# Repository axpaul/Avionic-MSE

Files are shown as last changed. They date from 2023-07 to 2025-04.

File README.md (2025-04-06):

# Avionic-MSE
*MSE experimental rocket avionic (On-board electronics), Version 2023 launched at C'space*

> *© 2023 Paul Miailhe, all rights reserved.*  
> *Material licensed under [→ CC BY-NC-SA 4.0](https://creativecommons.org/licenses/by-nc-sa/4.0)*

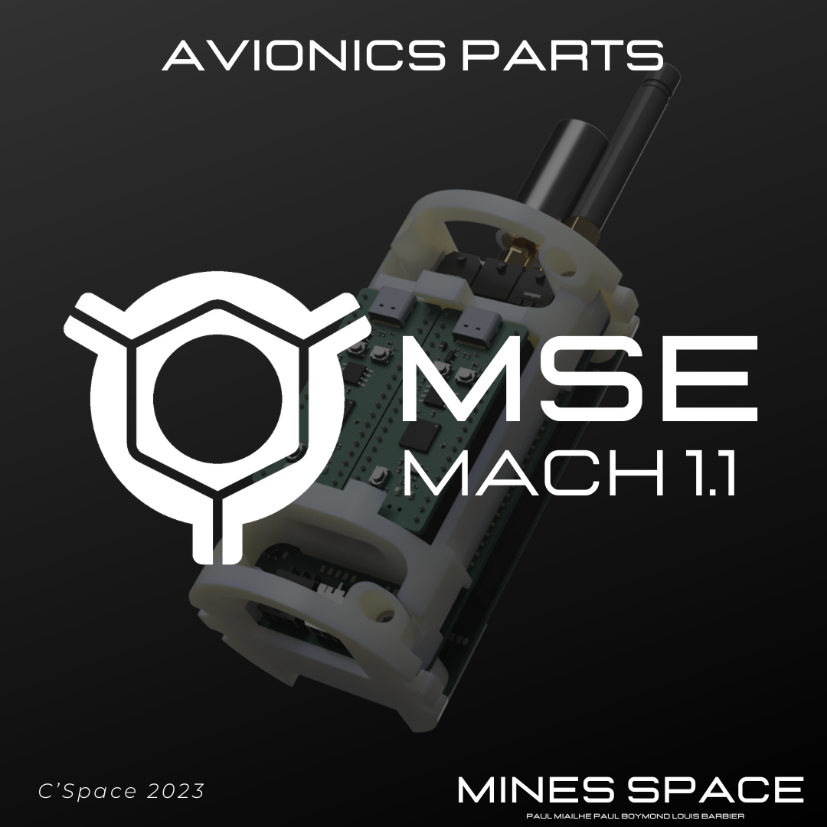
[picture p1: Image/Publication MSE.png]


Grabcad :
- https://grabcad.com/library/avionics-system-for-mse-rocket-1

---

# Projet MarSoniquE (MSE)

Le projet **MarSoniquE (MSE)**, également connu sous le nom de **Marsaut E**, vise à concevoir une fusée expérimentale robuste et adaptée aux vols supersoniques pour mener des études spécifiques dans ce domaine. À ce jour, aucune fusée expérimentale n’a réalisé de vol nominal avec des caractéristiques similaires lors des événements du **C’Space** sur le site d’essai du 1er RHP. En s’appuyant sur une démarche Open Source, le projet cherche à fournir un cadre technique permettant de relever ce défi.

Le développement s’appuie sur l’expérience acquise avec les avioniques des projets précédents **Marsaut 0** et **Marsaut 1**. L’objectif principal est de créer une structure résistante aux contraintes mécaniques d’un vol supersonique, avec des accélérations atteignant **28g** et des vibrations significatives dans le domaine transsonique. Par ailleurs, la crise actuelle des semi-conducteurs impose des choix restrictifs en termes de composants.

---

## Composants techniques

### Microcontrôleur
- **RP2040** : Microcontrôleur de Raspberry basé sur un cœur **ARM Cortex-M0+**.  
  Il intègre des fonctionnalités telles que la gestion de mémoire flash (Quad-SPI) et répond aux besoins du projet.

---

### Instrumentation

#### Capteurs analogiques
- **26PCGFA6D** : Capteur de pression différentiel pour la sonde Pitot, mesurant jusqu’à **250 PSI**.
  - **Amplificateur** : Utilisation de l’**INA121** pour amplifier proprement le signal.
  - **Convertisseur analogique-numérique** : **ADS1014** pour transformer le signal amplifié en données numériques exploitables.

#### Capteurs numériques
- **IMU MPU9250** : Capteur inertiel 6 axes, capable de mesurer des accélérations jusqu’à **16g**.  
- **LPS22HB** : Altimètre combinant mesures de pression et de température.  
- **GPS MAX-M10S** : Module GPS compact, opérationnel jusqu’à **80 000 m d’altitude**, **500 m/s** de vitesse et avec une dynamique maximale de **4g**.

---

### Transmission radio
- **SX1276** : Transcepteur LoRa fonctionnant sur **868 MHz**, permettant une communication longue portée et fiable.  
  Il est conçu pour fonctionner efficacement dans des conditions de faible signal grâce à sa sensibilité élevée et sa réduction de bruit intégrée.

---

### Stockage
- **W25Q128JV** : Mémoire flash **SPI de 128 Mbits** utilisée pour l’enregistrement des données en vol.

---

### Alimentation
- **LM340AT** : Régulateur de tension fournissant des tensions fixes de **5V**, **12V** et **15V**, avec une capacité de courant de **1A**.  
- **1210L110/16WR** : Fusible réarmable **PTC** protégeant le circuit contre les surintensités.

---

### Drivers et circuits
- **DRV8871DDARQ1** : Contrôleur de moteur à courant continu.  
  - Tension d’alimentation : **6,5V à 45V**.  
  - Courant de sortie : jusqu’à **3,6A**.  
  Ce composant est utilisé pour piloter les systèmes mécaniques, tels que la trappe de récupération.

- **74HC14D,653** : Porte logique inverseuse Schmitt.  
  Elle stabilise les signaux bruités des fins de course des moteurs et garantit un fonctionnement sûr du système de récupération.

---

## Architecture des cartes et choix des composants

### Cartes développées en interne

Deux cartes principales de l’avionique de la fusée ont été spécialement conçues et fabriquées pour répondre aux exigences spécifiques du projet :

1. **Carte avionique** :  
   - Regroupe les composants essentiels tels que le module **LoRa (SX1276)**, le **GPS (MAX-M10S)**, les **drivers moteurs** et les **portes inverseuses (74HC14D,653)** pour le traitement des signaux.  
   - Inclut également un **buzzer** destiné aux alertes sonores durant les phases critiques.

2. **Carte interface** :  
   - Assure la gestion de l’alimentation ainsi que l’isolation numérique pour protéger et séparer les signaux.  
   - Offre des connecteurs dédiés pour accueillir des capteurs et des cartes auxiliaires, y compris celles équipées de microcontrôleurs.

Ces cartes sur mesure ont été développées pour répondre aux contraintes mécaniques, environnementales et fonctionnelles du projet, tout en garantissant une intégration modulaire et flexible.

---

### Cartes commerciales intégrées

En complément des cartes développées en interne, des cartes électroniques standard commercial ont été choisies pour leur disponibilité et leur coût réduit, tout en répondant aux besoins du projet :
- **RP2040-YD avec 128 Mbits de flash** : Une carte microcontrôleur RP2040 compacte équipée de mémoire flash et conçue sous le format Pico.  
- **Carte capteurs 10DOF** : Fournie par **Waveshare**, cette carte intègre des capteurs inertiels et un baromètre pour mesurer des paramètres comme les accélérations et la pression. Plus d'informations disponibles ici : [Waveshare Pico-10DOF-IMU](https://www.waveshare.com/pico-10dof-imu.htm).

---

### Synoptic

Le schéma synotique du projet avionique :
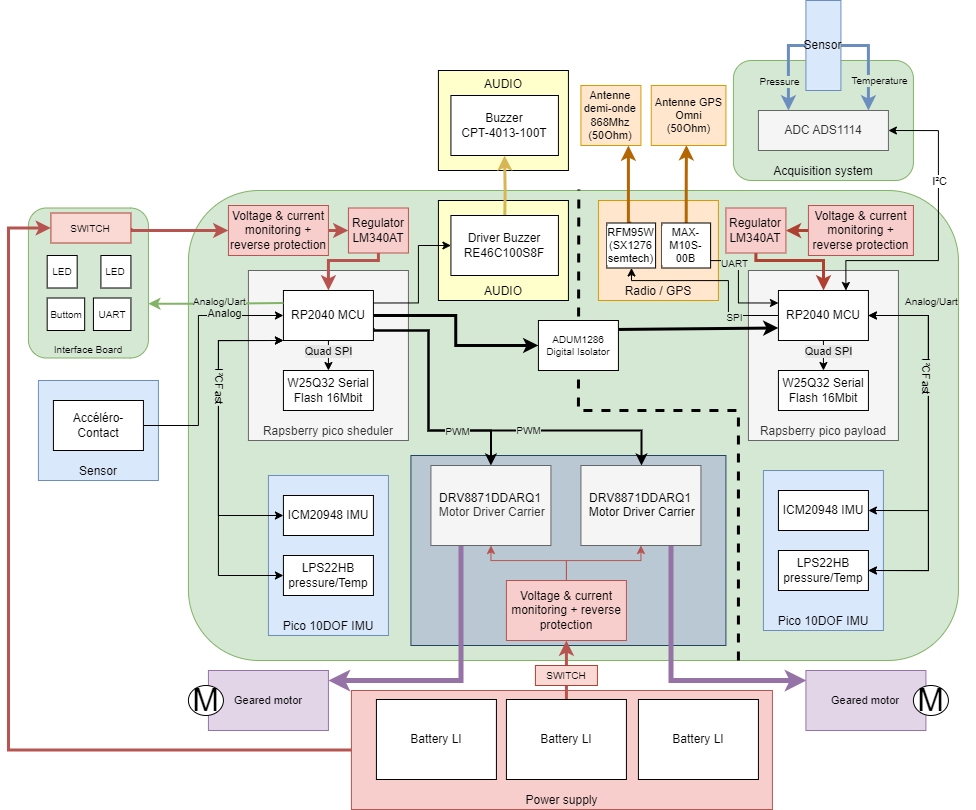
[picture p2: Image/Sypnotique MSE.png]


---

### Pinout séquenceur & sensor :

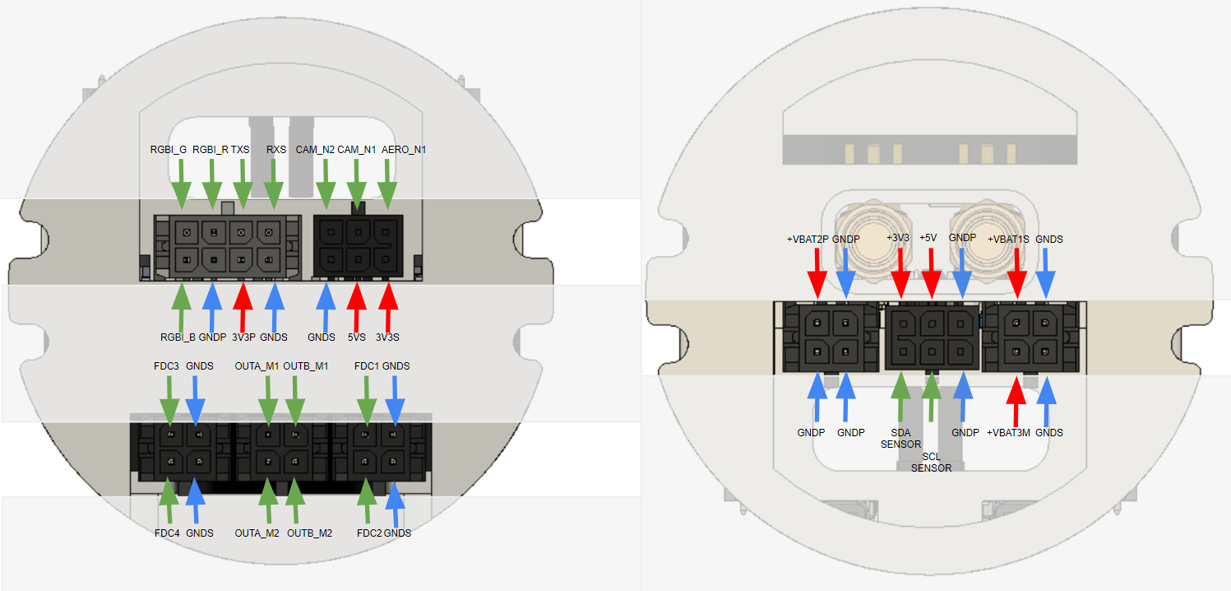
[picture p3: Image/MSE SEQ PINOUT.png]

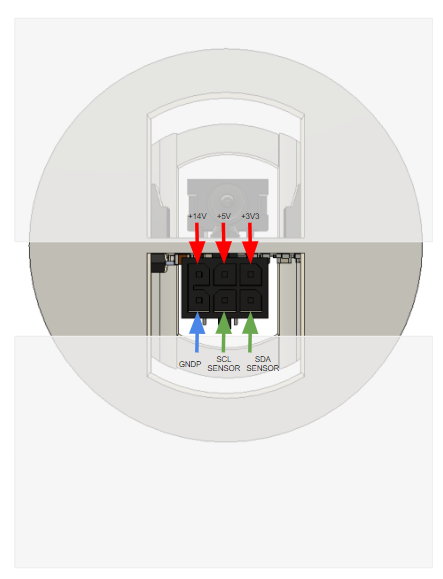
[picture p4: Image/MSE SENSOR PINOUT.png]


---

### Tableau des cartes :

| 3D | Routing  | Description |
|:---:|:---:|:---:|
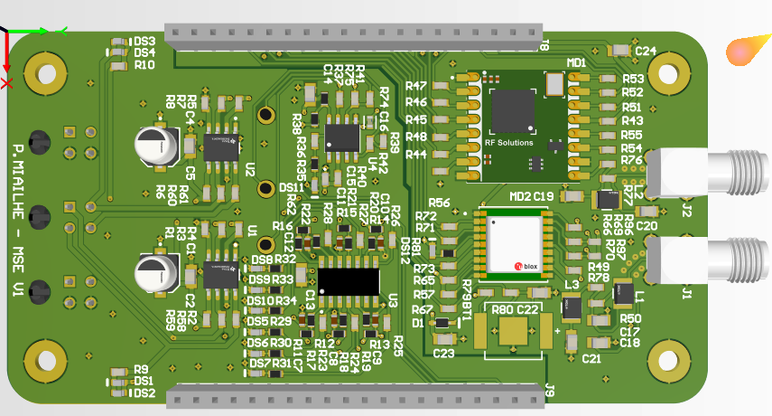
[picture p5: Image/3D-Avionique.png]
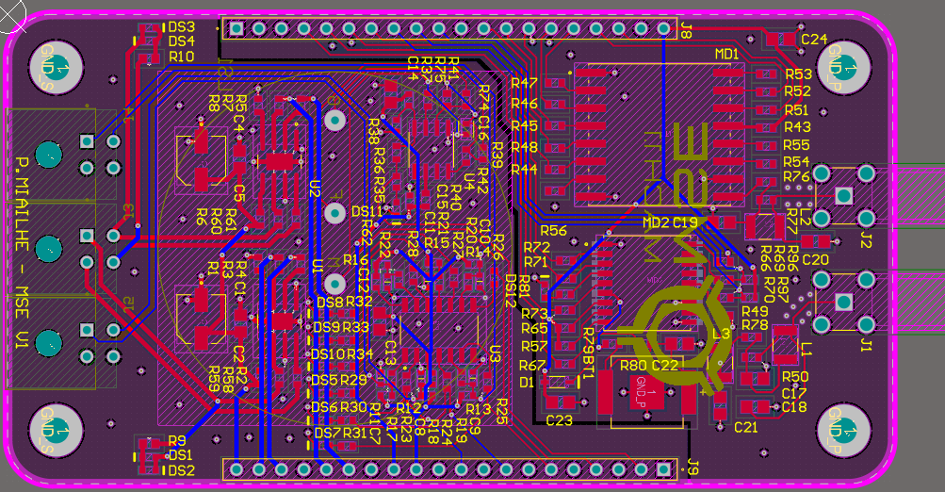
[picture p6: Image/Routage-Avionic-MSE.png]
|  |  | Carte avionique V°1|
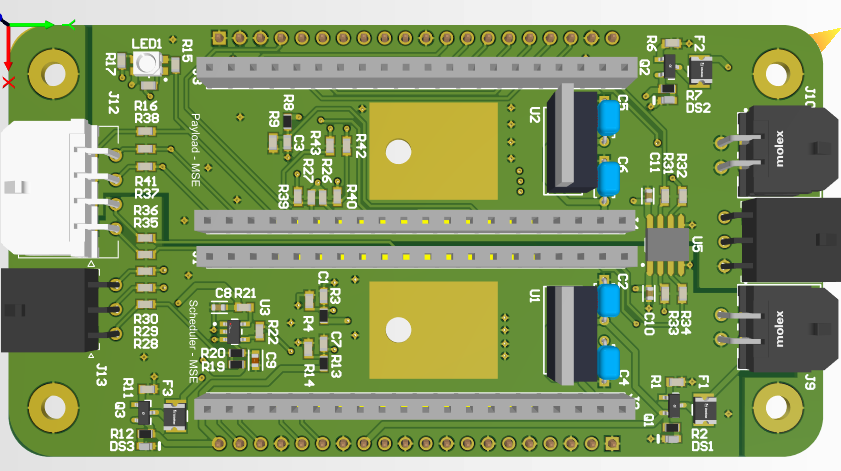
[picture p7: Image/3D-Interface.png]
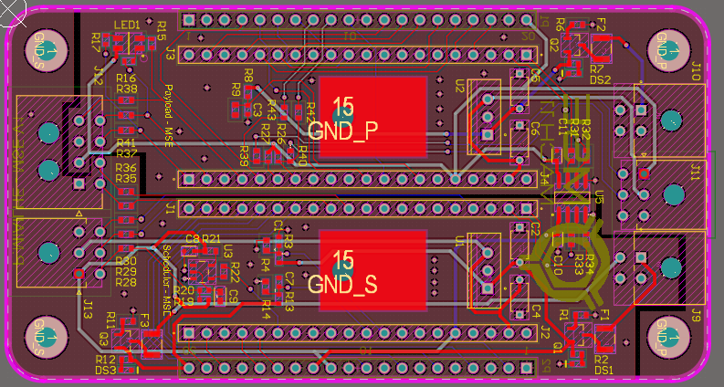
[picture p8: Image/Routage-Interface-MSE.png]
|  |  | Carte interface V°1 |
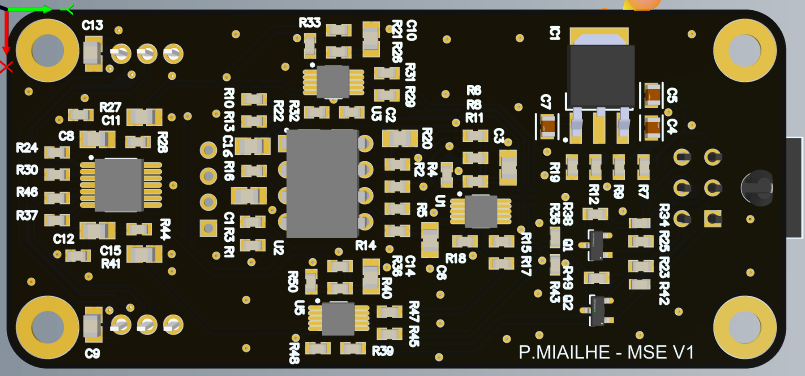
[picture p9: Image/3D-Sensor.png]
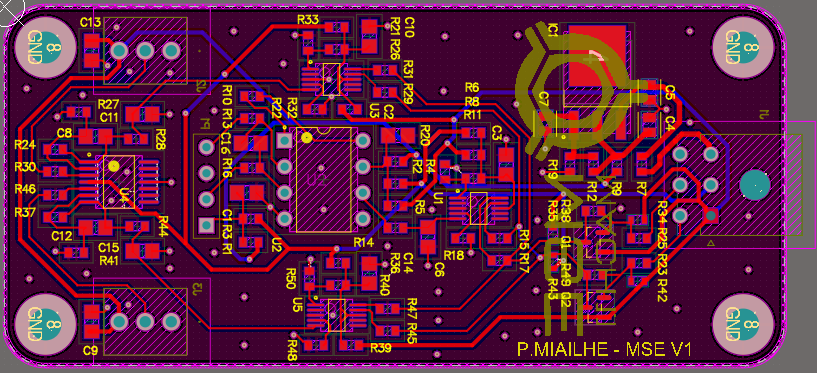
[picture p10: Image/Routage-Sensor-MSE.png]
|   |   | Carte capteur analogique V°1 |
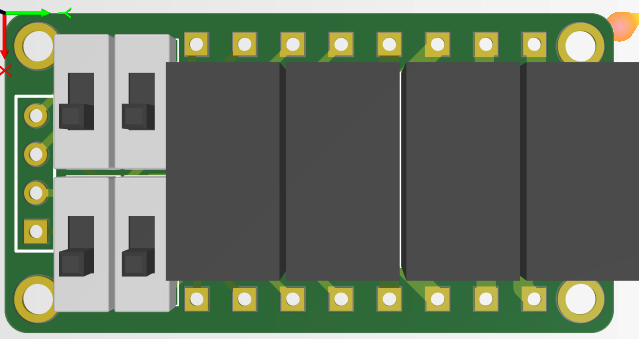
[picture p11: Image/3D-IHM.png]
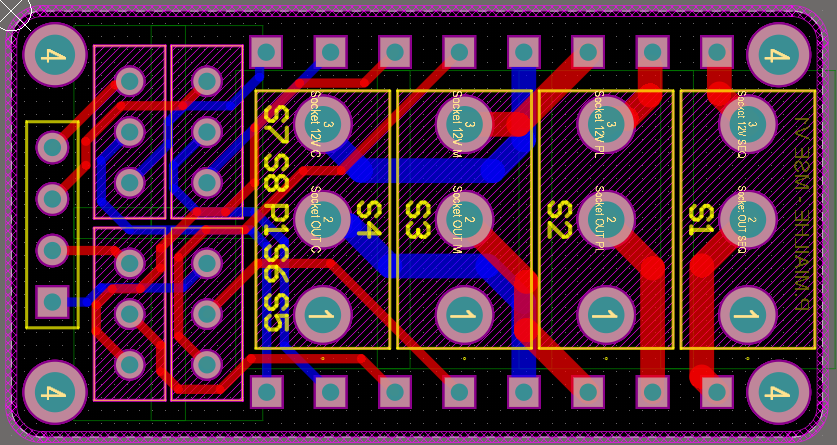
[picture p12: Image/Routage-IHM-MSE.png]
|   |   | Carte IHM V°1 |

## Licence 



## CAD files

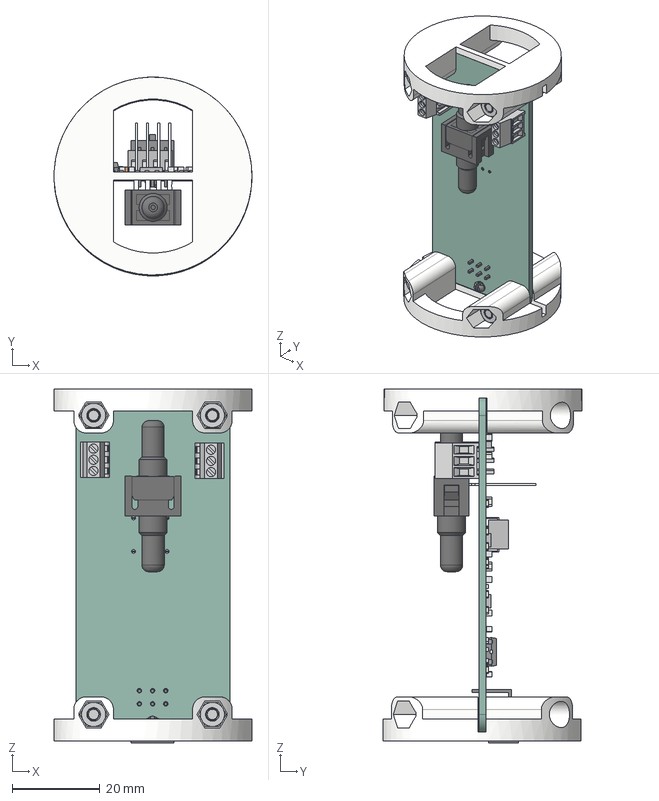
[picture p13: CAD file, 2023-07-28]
CAO/Assemblage PL V1 MSE v19.step
45.0 x 45.2 x 80.5 mm
90592A085_Steel Hex Nut x 4
Extruded x 14
Extruded (1) x 7
Extruded (2) x 78
Extruded (3) x 39
Extruded (4) x 12
Extruded (5) x 6
2125280601 v1
Extruded (6) x 3
Extruded (7)
Extruded (8)
Extruded (9) x 8
Extruded (10) x 8
Extruded (11) x 8
MAC4DCMT4G_5
MAC4DCMT4G
MAC4DCMT4G_4
MAC4DCMT4G_3
MAC4DCMT4G_2
Murata Logo 3 x 3
Extruded (12) x 12
Extruded (13) x 6
sps-siot-2xpcxxa6d-cad-model-ciid-162559
91290A123_Alloy Steel Socket Head Screw x 4

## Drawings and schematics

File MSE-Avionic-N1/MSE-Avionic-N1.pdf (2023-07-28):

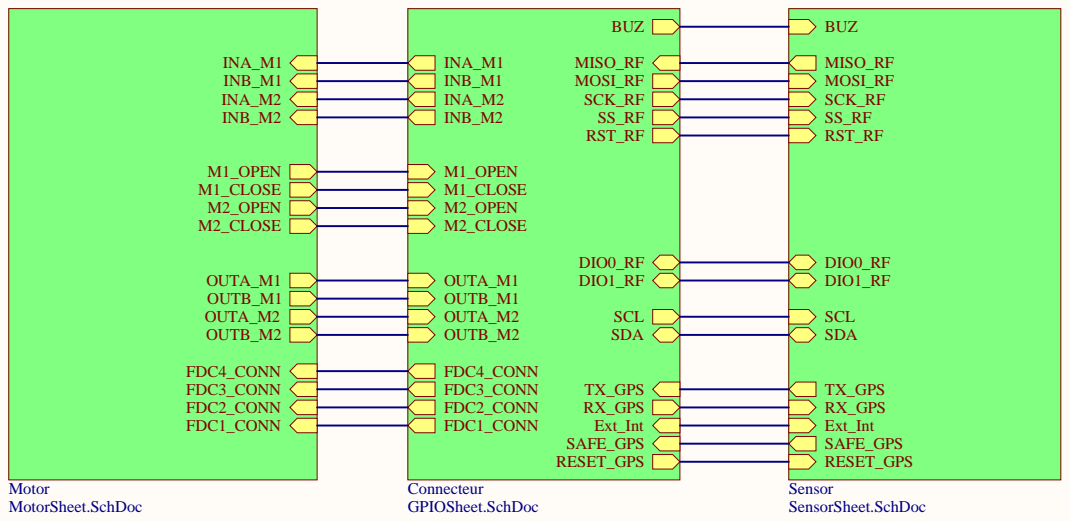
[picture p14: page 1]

Size A | Number | Revision V°1

Date: 7/28/2023 | Sheet of
File: C:\Users\..\MainSheet.SchDoc | Drawn By: Paul Miailhe

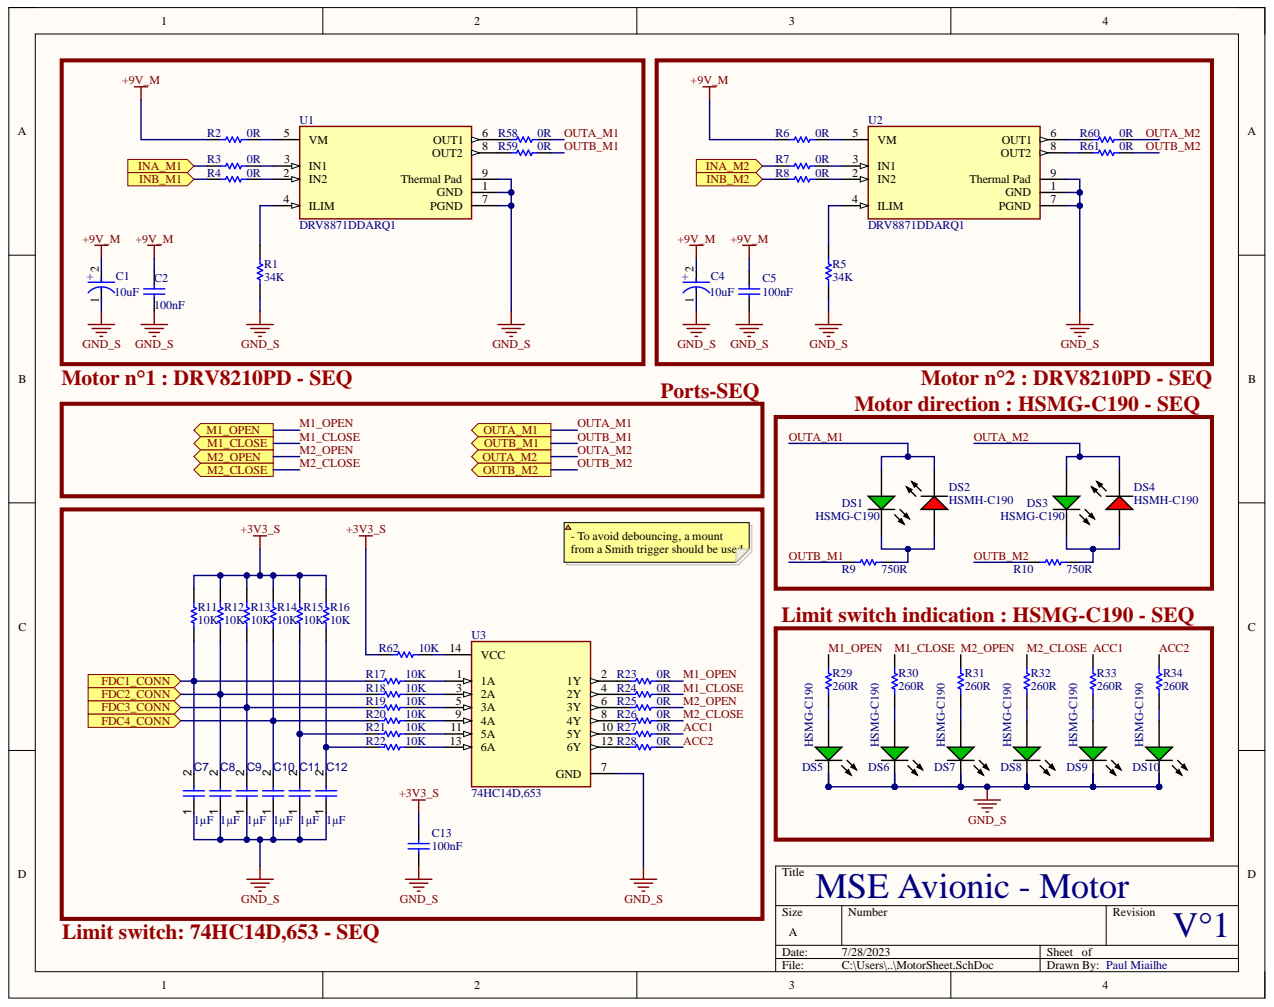
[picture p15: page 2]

Motor direction : HSMG-C190 - SEQ

- To avoid debouncing, a mount
from a Smith trigger should be used

Limit switch indication : HSMG-C190 - SEQ

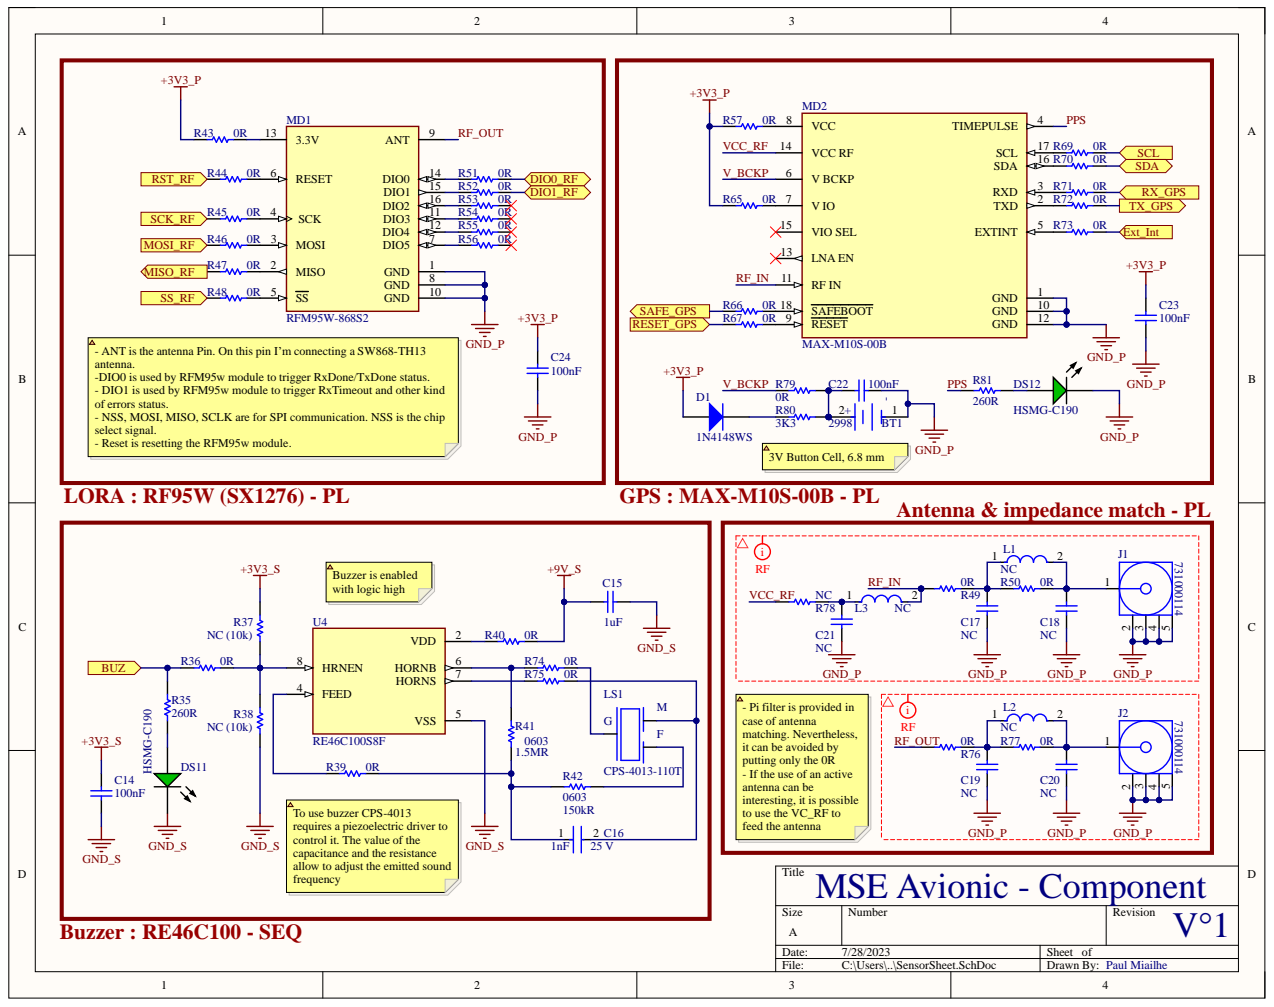
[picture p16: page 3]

- ANT is the antenna Pin. On this pin I’m connecting a SW868-TH13
antenna.
-DIO0 is used by RFM95w module to trigger RxDone/TxDone status.
- DIO1 is used by RFM95w module to trigger RxTimeout and other kind
of errors status.
- NSS, MOSI, MISO, SCLK are for SPI communication. NSS is the chip
select signal.
- Reset is resetting the RFM95w module.

Antenna & impedance match - PL

- Pi filter is provided in
case of antenna
matching. Nevertheless,
it can be avoided by
putting only the 0R
- If the use of an active
antenna can be
interesting, it is possible
to use the VC_RF to
feed the antenna

To use buzzer CPS-4013
requires a piezoelectric driver to
control it. The value of the
capacitance and the resistance
allow to adjust the emitted sound
frequency

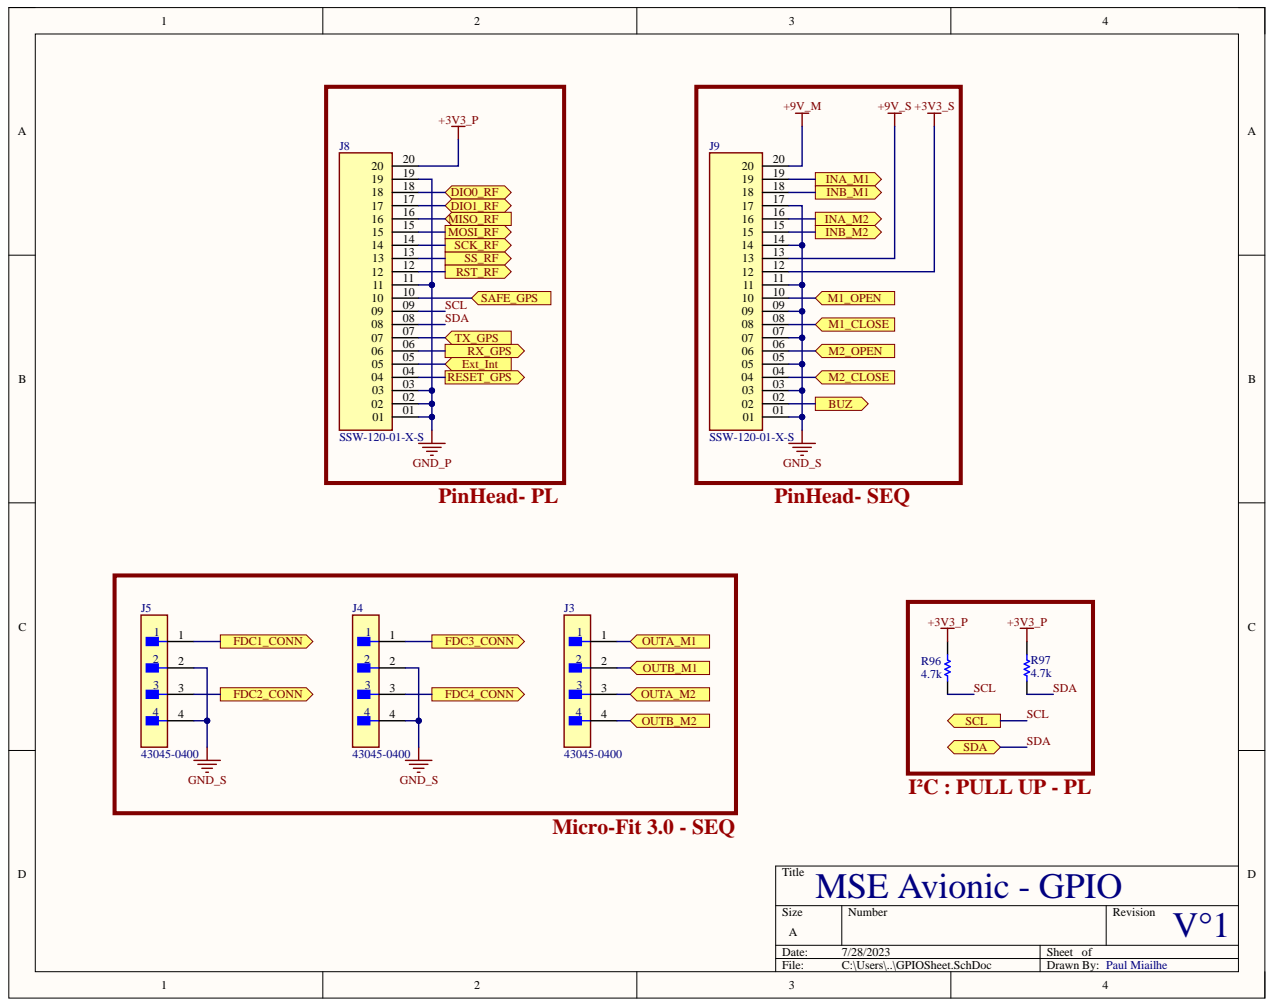
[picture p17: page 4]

SDA
I²C : PULL UP - PL

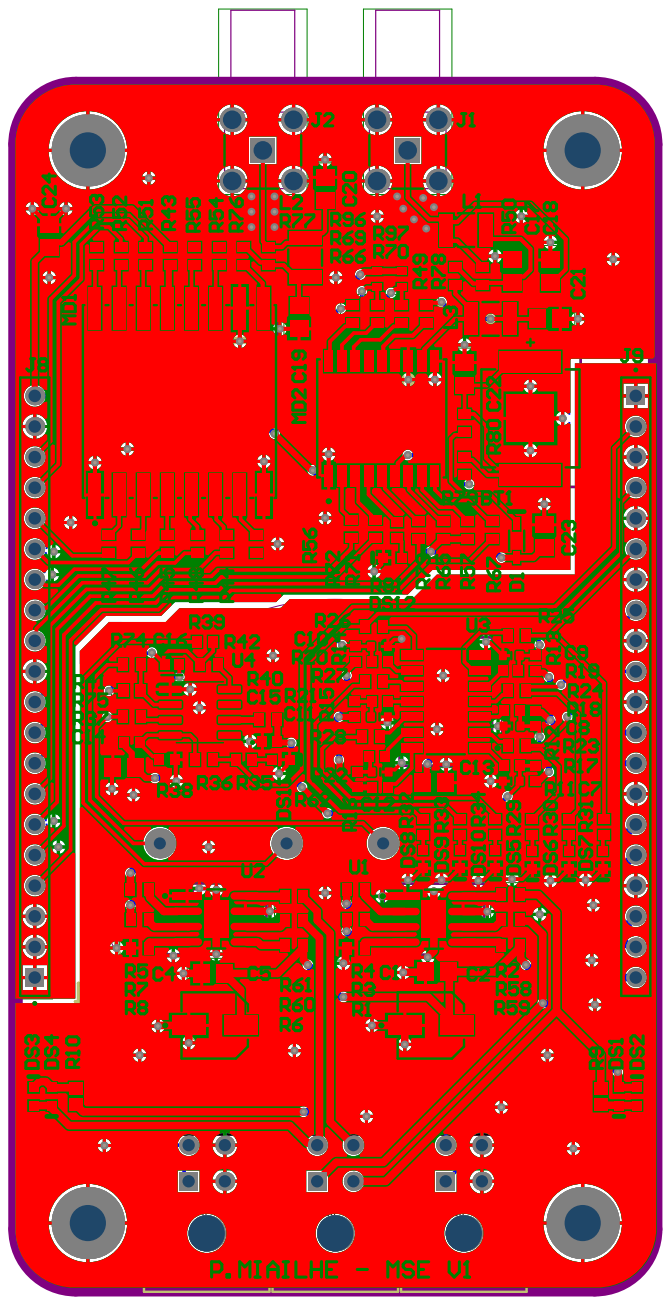
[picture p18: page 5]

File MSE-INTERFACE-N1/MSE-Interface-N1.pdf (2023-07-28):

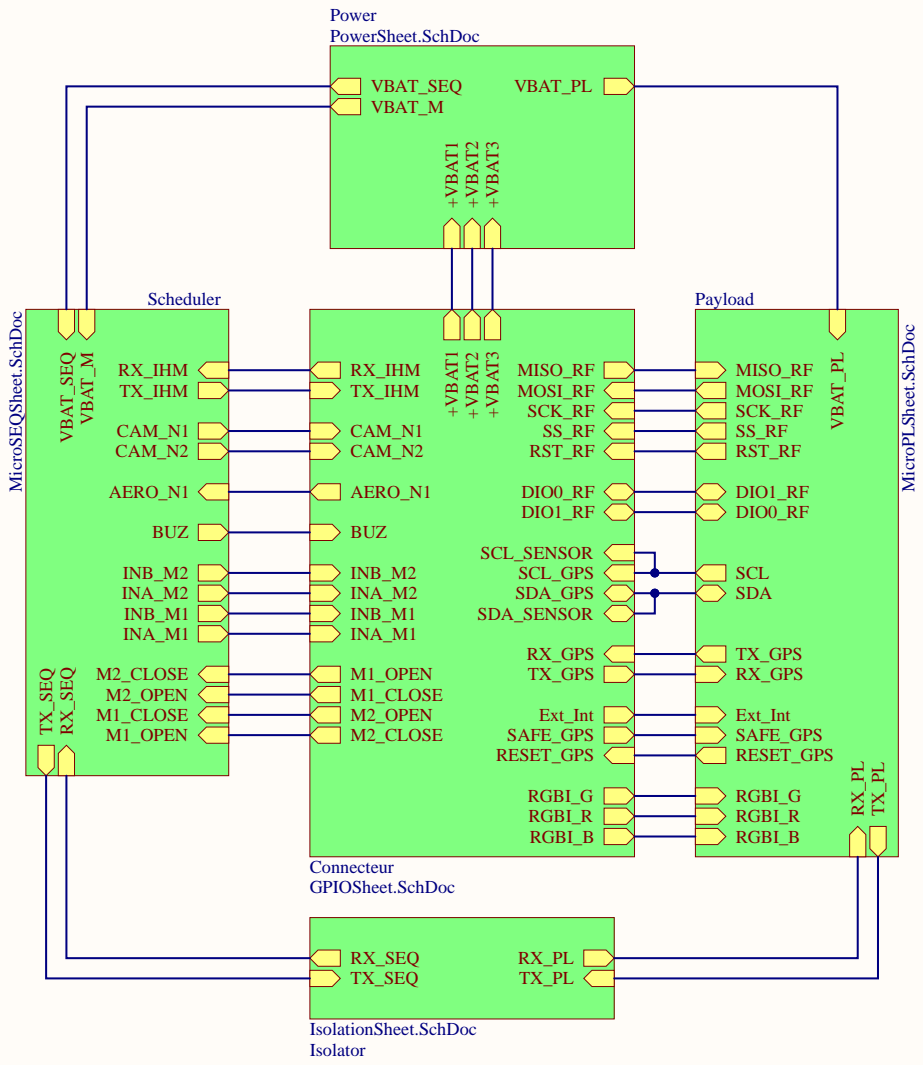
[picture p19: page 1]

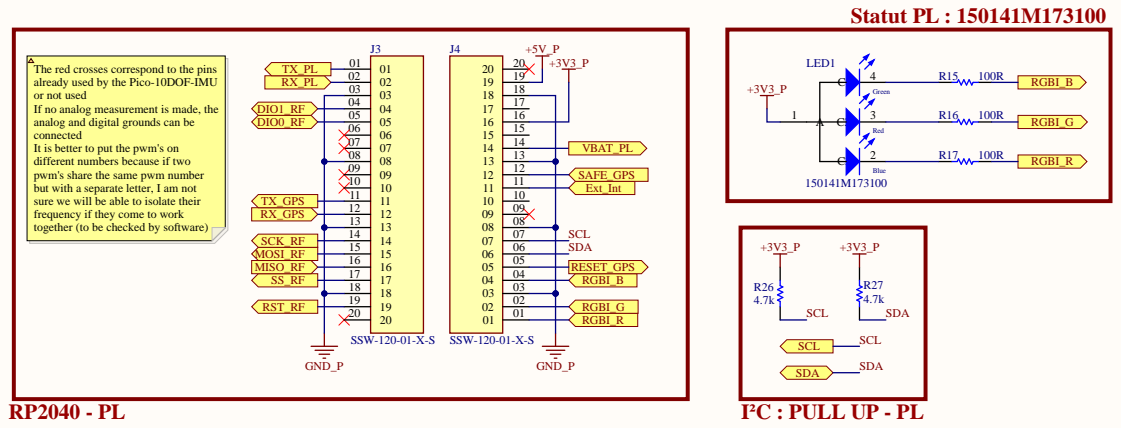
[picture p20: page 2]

The red crosses correspond to the pins
already used by the Pico-10DOF-IMU
or not used
If no analog measurement is made, the
analog and digital grounds can be
connected
It is better to put the pwm's on
different numbers because if two
pwm's share the same pwm number
but with a separate letter, I am not
sure we will be able to isolate their
frequency if they come to work
together (to be checked by software)

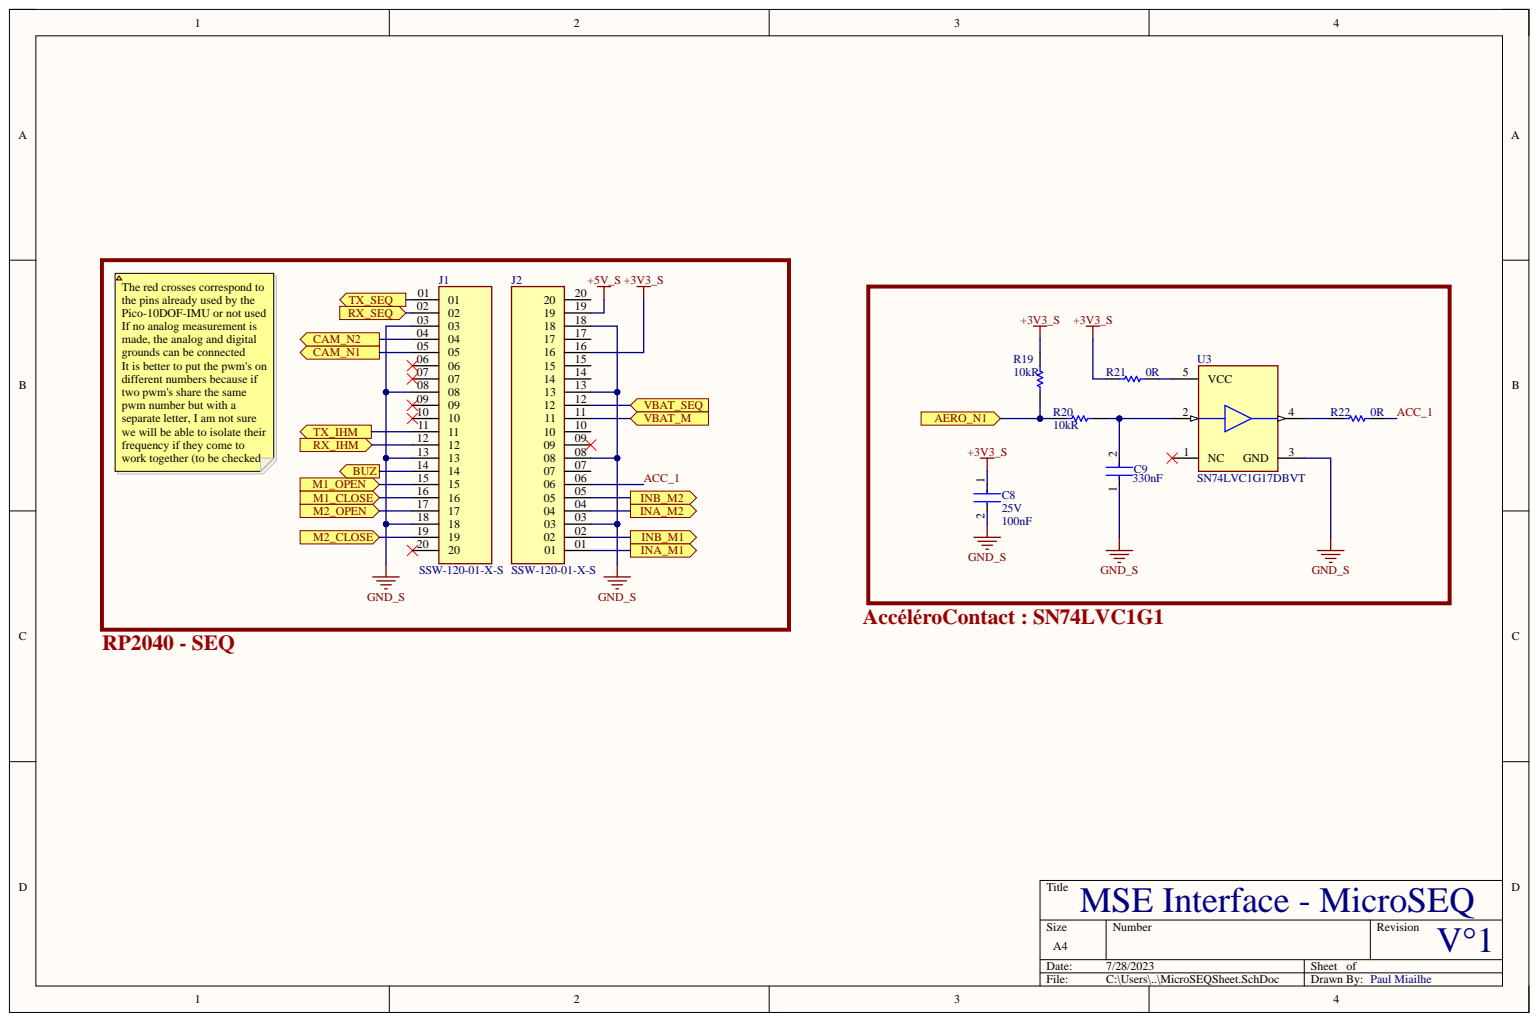
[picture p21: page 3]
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

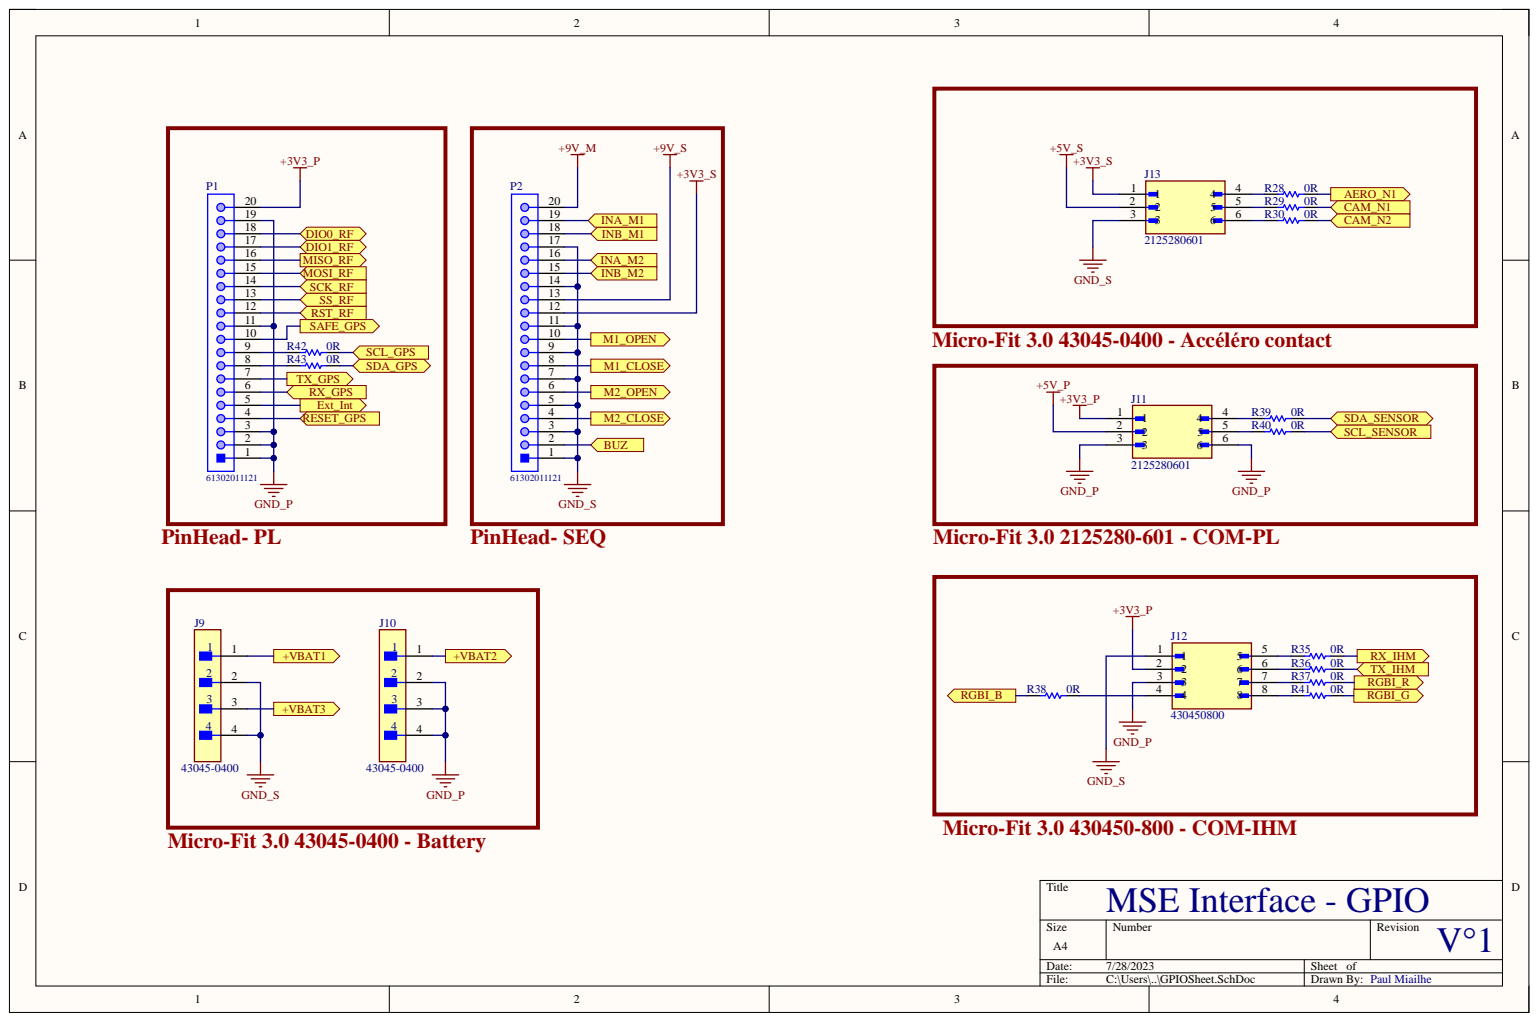
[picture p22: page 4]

Micro-Fit 3.0 43045-0400 - Accéléro contact

Micro-Fit 3.0 2125280-601 - COM-PL

Micro-Fit 3.0 430450-800 - COM-IHM

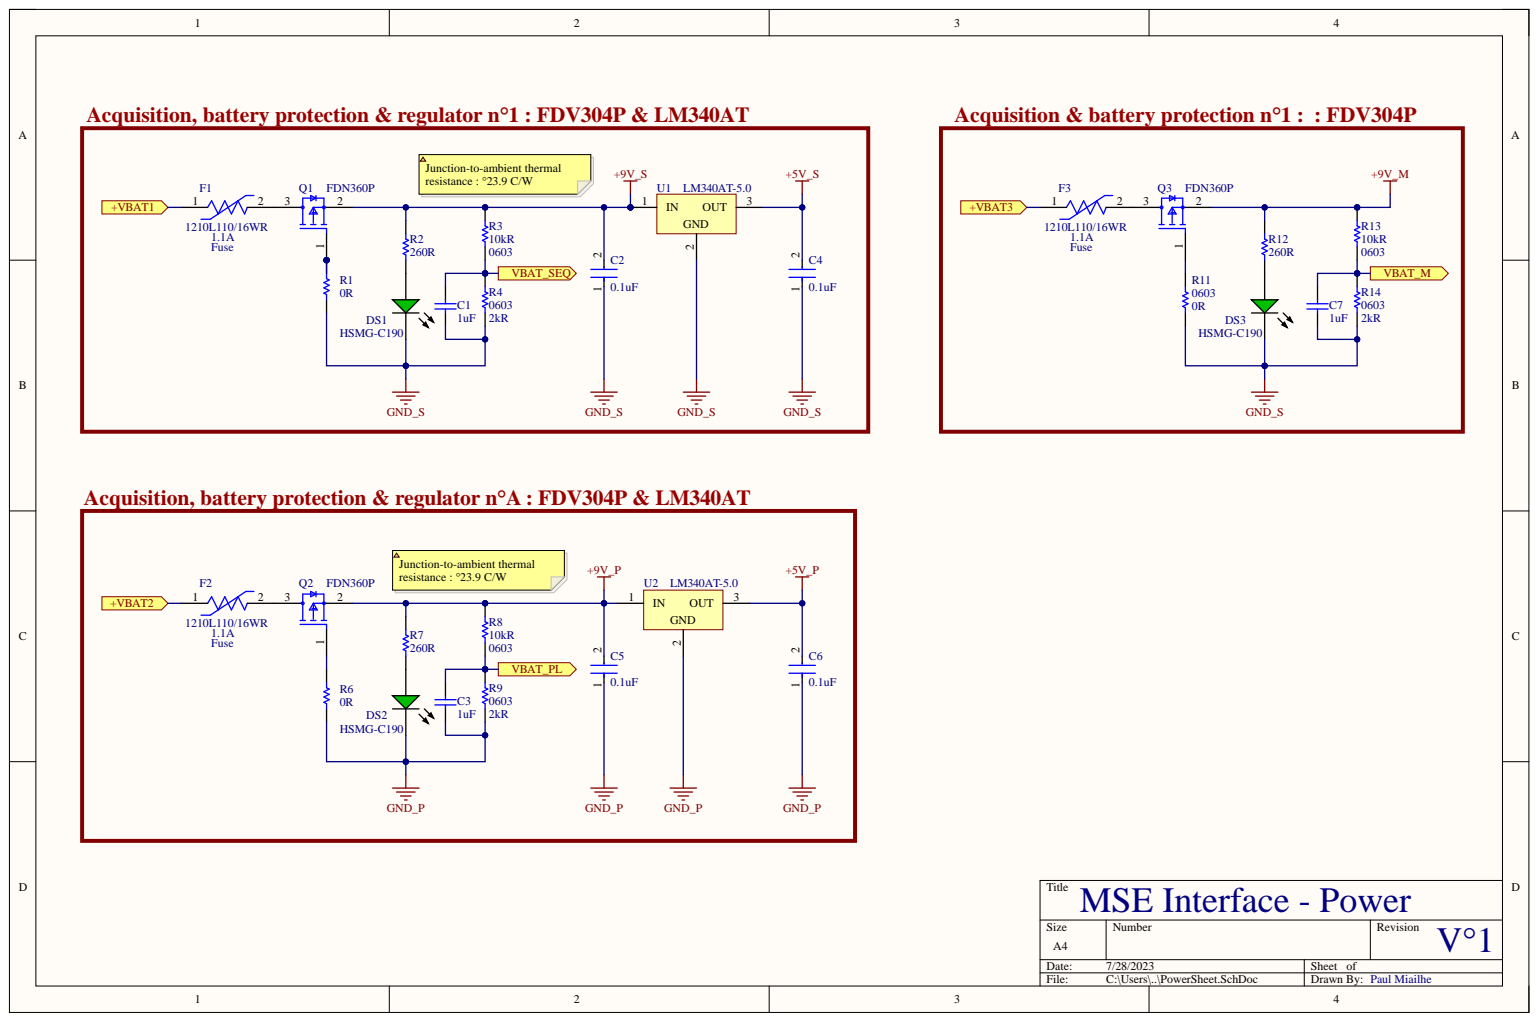
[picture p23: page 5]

Acquisition, battery protection & regulator n°1 : FDV304P & LM340AT

Junction-to-ambient thermal
resistance : °23.9 C/W

Acquisition, battery protection & regulator n°A : FDV304P & LM340AT

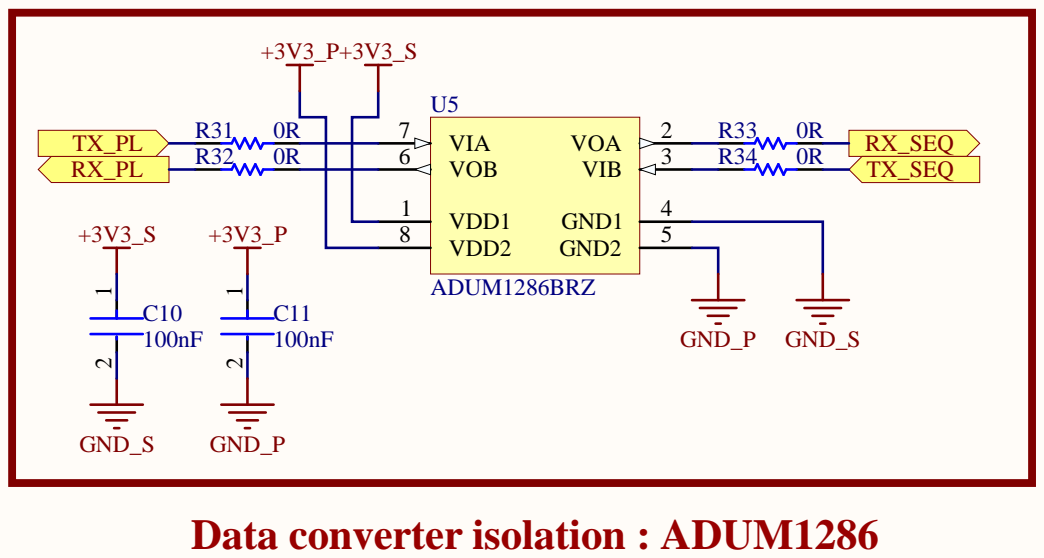
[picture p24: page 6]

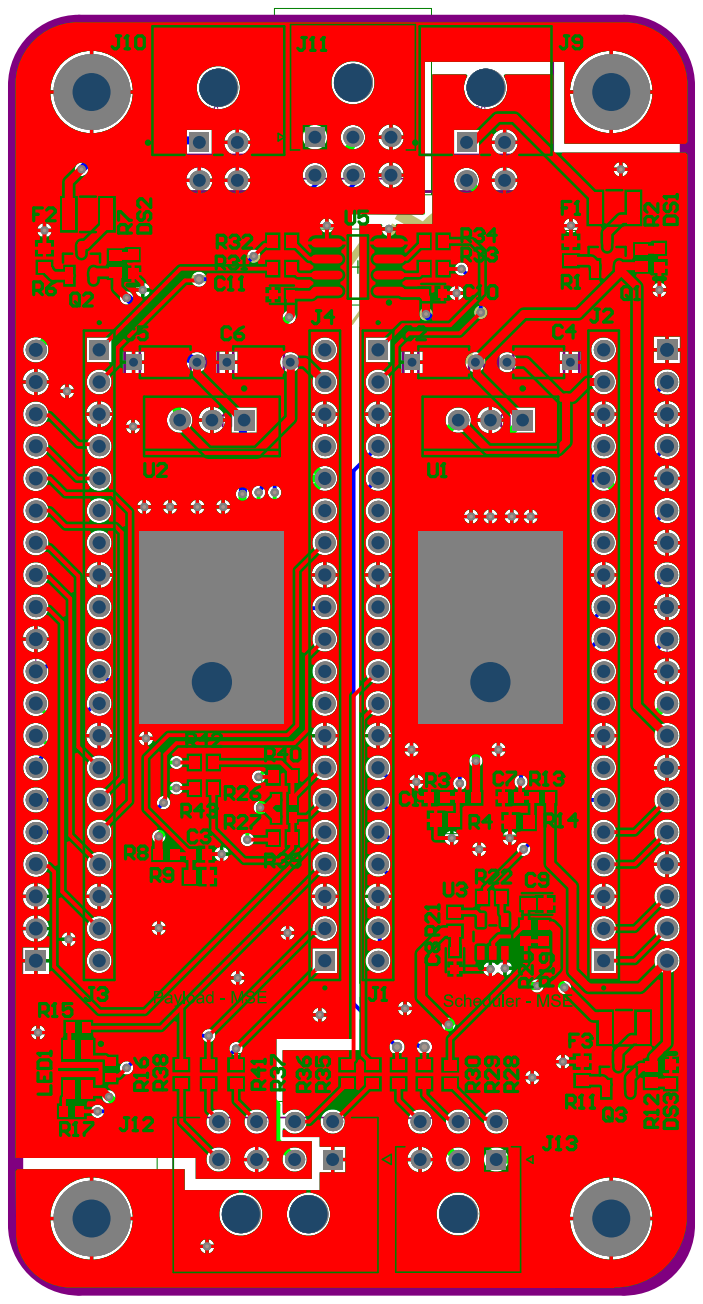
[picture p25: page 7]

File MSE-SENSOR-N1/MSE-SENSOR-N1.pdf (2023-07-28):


4 | AIN1 5 | 9

GND

26PCG
- Capteur en pont de wheastone ayant un span de
- Utilisation d'un AOP instrumentale INA 121,
sachant que Vo = G * (Vi(+) - Vi(-)) & G = 1 +
50K/Rg alors G = 33 & Rg
- Lecture capteur 1ms = > 1kHz donc filtre RC
pour r
C = 1uF en donnant Fo = 1591hz (1/2

é un filtre passe bas passif R = 100R et




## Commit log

2023-07-28 add cao
    [Assemblage PL V1 MSE v19.step]
2024-01-15 Correction Pinout MSE sensor

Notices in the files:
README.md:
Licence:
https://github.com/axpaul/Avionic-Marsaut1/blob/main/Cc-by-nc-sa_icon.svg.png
